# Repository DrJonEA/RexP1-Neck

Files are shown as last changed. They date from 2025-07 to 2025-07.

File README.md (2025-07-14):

# RexP1-Neck
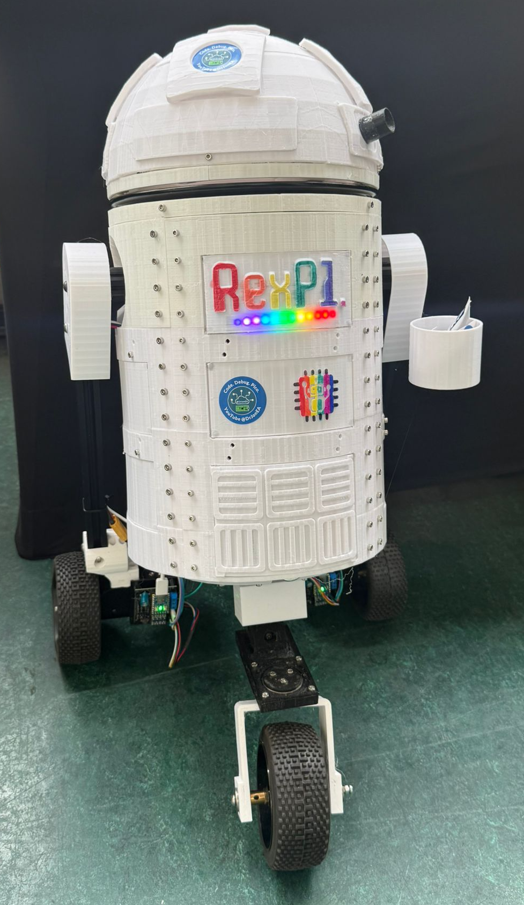
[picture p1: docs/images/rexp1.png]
isolated

Drive wheel for my RexP1 Astro Droid Project based on a RP2040Zero board. This Repo repreents the drive wheel subsystem for RexP1.

Checkout the [videos guides](https://www.youtube.com/playlist?list=PLspDyukWAtRUPNdlktaOdk7os9TfTEFh1) to the project over on my [YouTube Channel DrJonEA](https://youtube.com/@drjonea).
 
## RexP1 Intro
RexP1 is a reimagined Star War's inspired Astro Droid based on the R series Droids. It is based on Raspberry PI 5, RP2040 and RP2350 boards. It's control system is a distributed net based on ROS2 and MicroROS frameworks.

All my work on RexP1 is available to  my sponsors. That includes not just this submodule but all the submodules, the build instructions, PCB designs, STL files, CAD designs and most important acess to me to ask questions. Take a look at the sponsorship button on the github repo.

## The Repo
This repo includes the PCB design for the dome rotation and tilt  with assoicated documentation. It also includes the firmware for a RP2040Zero which acts as a ROS2 Node to control the Dome.

## Libraries
Note libraries have not been included as submodules in this repo. That is because I wanted just a single copy of the libraries in the master repo for RexP1. So take note of the [lib documentation](docs/Libraries.md).

## Build process
The firmware should build like most *complex* Pico SDK firmware projects. Normal procedure:
```
mkdir build
cd build
cmake ..
make
```
If you have ninja use that instead of make for Windows. Just make sure you update the CMakelists.txt to point to your libraries and that the environment variable PICO_SDK_PATH is defined to point to the SDK.

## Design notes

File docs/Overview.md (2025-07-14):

# Project Overview: 
REXP1 is reimagined, modular Star Wars-inspired droid that blends mechanical engineering, electronics, and thematic flair. Designed for both mobility and character, it features a dual-mode rotating body that shifts between relaxed drive possition and alert postures, driven by bus servos and integrated with interactive LED lighting for expressive behavior.

# Key Technical Highlights:

## Dome Rotation: 
Powered by a modified 28BYJ-48 stepper motor configured for two-phase operation and driven via a DRV8825 motor driver. A Hall sensor (A1104) is used for zero-point calibration, ensuring precise rotation positioning.

## Body Tilt Mechanism: 
Built around bus servos with direct UART communication through an RP2040, complemented by a braced gear drive for torque management. Initial gear designs were iterated to improve stability under growing load.

## Microcontroller & Control Firmware: 
The RP2040Zero microcontroller hosts firmware which orchestrates movement via Micro ROS integration. Stepper and servo controls are abstracted into modular classes like Stepper, JointAgent, and LX16A, enabling joint state publishing and jog-based movement control.

## Visual Effects & Expression: 
Equipped with WS2812B (NeoPixel) LED bars managed via a custom LED Bar Agent. Patterns include rainbow sequences and a Knight Rider–inspired "KITT" sweep, with pride-themed color support to reflect community values and demonstration context.

## Expandable Connectivity: 
The PCB (fabricated by PCBWay) includes multiple servo outputs (PWM and UART) and support for additional peripherals, allowing future upgrades like tool arms and sensory modules.

## Creative & Thematic Elements: 
The build fuses classic sci-fi aesthetics with modern electronics, aiming to evolve REX-P1 into a more expressive and interactive robotic character. Jon’s storytelling adds depth, portraying the development journey with humor and candid insights into design challenges.

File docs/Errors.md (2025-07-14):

# Known errors

<ol>
<li>Signal diode is wrong way around on PCB</li>
<li>RexP1 has grown beyond BUSServos for tilting</li>
</ol>

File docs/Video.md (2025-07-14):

# Video Guides

[This video](https://youtu.be/UPuPh0Mcucg) talks about the PCB design for the Dome rotation and tilt mechanism.

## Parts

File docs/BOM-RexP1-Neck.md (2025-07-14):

# Bill of Materials

This is a BOM for the controller PCB. Headerpins will also be needed for some of the connectors.

|Reference |Footprint	 |	Qty	| Link | Notes
|---|---|----|---|---|
|A1|Pololu_Breakout_DRV8825| 1|https://amzn.to/3GIwLjC||
|BS1,BS2|JST_XH_B3B-XH-AM_1x03_P2.50mm_Vertical|2| | For HiWonder LX16A|
|C1|0.1uF C_Disc_D4.7mm_W2.5mm_P5.00mm|1|||
|C2,C3|1000uF CP_Radial_D8.0mm_P5.00mm|2|||
|D2|1N4148|1|https://assets.nexperia.com/documents/data-sheet/1N4148_1N4448.pdff|||
|J1|Stepper JST_XH_B4B-XH-AM_1x04_P2.50mm_Vertical|1|||
|J2|uart0 PinHeader_1x03_P2.54mm_Vertical,"1"|||
|J3|GND to GNDA PinHeader_1x02_P2.54mm_Vertical|1||Allows jumper to connect grounds|
|J4|Hall Sensor PinHeader_1x03_P2.54mm_Vertical|1|||
|J5,SV1,SV2,SV3,SV4,SV5| PinHeader_1x03_P2.54mm_Vertical|6||Used for Servos|
|J6| WS2812B-1 Conn_01x04_Pin|2|||
|P2|12V SCREWTERMINAL-5MM-2|1|||
|P3|6V|SCREWTERMINAL-5MM-2|1|||
|R1|RResistor_THT|1|||
|R2|220R|Resistor_THT|1|||
|R3|10K|Resistor_THT|1|||
|RZ1|RP2040-Zero|RP2040-Zero||1||
|SW1|SW_SPST |1|SW_PUSH_6mm||
|U1|LvlShift2Bi||1|| 2 channel level shifter|
|U2|A1104xLH|1|HAll Sensor||

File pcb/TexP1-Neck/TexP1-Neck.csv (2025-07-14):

Reference | Value | Footprint | Datasheet | Qty | DNP
A1 | Pololu_Breakout_DRV8825 | Module:Pololu_Breakout-16_15.2x20.3mm | https://www.pololu.com/product/2982 | 1
BS1,BS2 | Bus Servo | Connector_JST:JST_XH_B3B-XH-AM_1x03_P2.50mm_Vertical | ~ | 2
C1 | 0.1uF | Capacitor_THT:C_Disc_D4.7mm_W2.5mm_P5.00mm | ~ | 1
C2,C3 | 1000uF | Capacitor_THT:CP_Radial_D8.0mm_P5.00mm | ~ | 2
D2 | 1N4148 | Diode_THT:D_DO-35_SOD27_P7.62mm_Horizontal | https://assets.nexperia.com/documents/data-sheet/1N4148_1N4448.pdf | 1
J1 | Stepper | Connector_JST:JST_XH_B4B-XH-AM_1x04_P2.50mm_Vertical | ~ | 1
J2 | uart0 | Connector_PinHeader_2.54mm:PinHeader_1x03_P2.54mm_Vertical | ~ | 1
J3 | GND to GNDA | Connector_PinHeader_2.54mm:PinHeader_1x02_P2.54mm_Vertical | ~ | 1
J4 | Hall Sensor | Connector_PinHeader_2.54mm:PinHeader_1x03_P2.54mm_Vertical | ~ | 1
J5,SV1,SV2,SV3,SV4,SV5 | Conn_01x03_Pin | Connector_PinHeader_2.54mm:PinHeader_1x03_P2.54mm_Vertical | ~ | 6
J6,WS2812B-1 | Conn_01x04_Pin | Connector_PinHeader_2.54mm:PinHeader_1x04_P2.54mm_Vertical | ~ | 2
P2 | 12V | Connectors:SCREWTERMINAL-5MM-2 | ~ | 1
P3 | 6V | Connectors:SCREWTERMINAL-5MM-2 | ~ | 1
R1 | R | Resistor_THT:R_Axial_DIN0207_L6.3mm_D2.5mm_P10.16mm_Horizontal | ~ | 1
R2 | 220R | Resistor_THT:R_Axial_DIN0207_L6.3mm_D2.5mm_P10.16mm_Horizontal | ~ | 1
R3 | 10K | Resistor_THT:R_Axial_DIN0207_L6.3mm_D2.5mm_P10.16mm_Horizontal | ~ | 1
RZ1 | RP2040-Zero | RP2040-Zero-Kicad:RP2040-Zero |  | 1
SW1 | SW_SPST | Button_Switch_THT:SW_PUSH_6mm | ~ | 1
U1 | LvlShift | JonLib:LvlShift2Bi |  | 1
U2 | A1104xLH | Package_TO_SOT_SMD:SOT-23W | https://www.allegromicro.com/-/media/files/datasheets/a110x-datasheet.ashx | 1

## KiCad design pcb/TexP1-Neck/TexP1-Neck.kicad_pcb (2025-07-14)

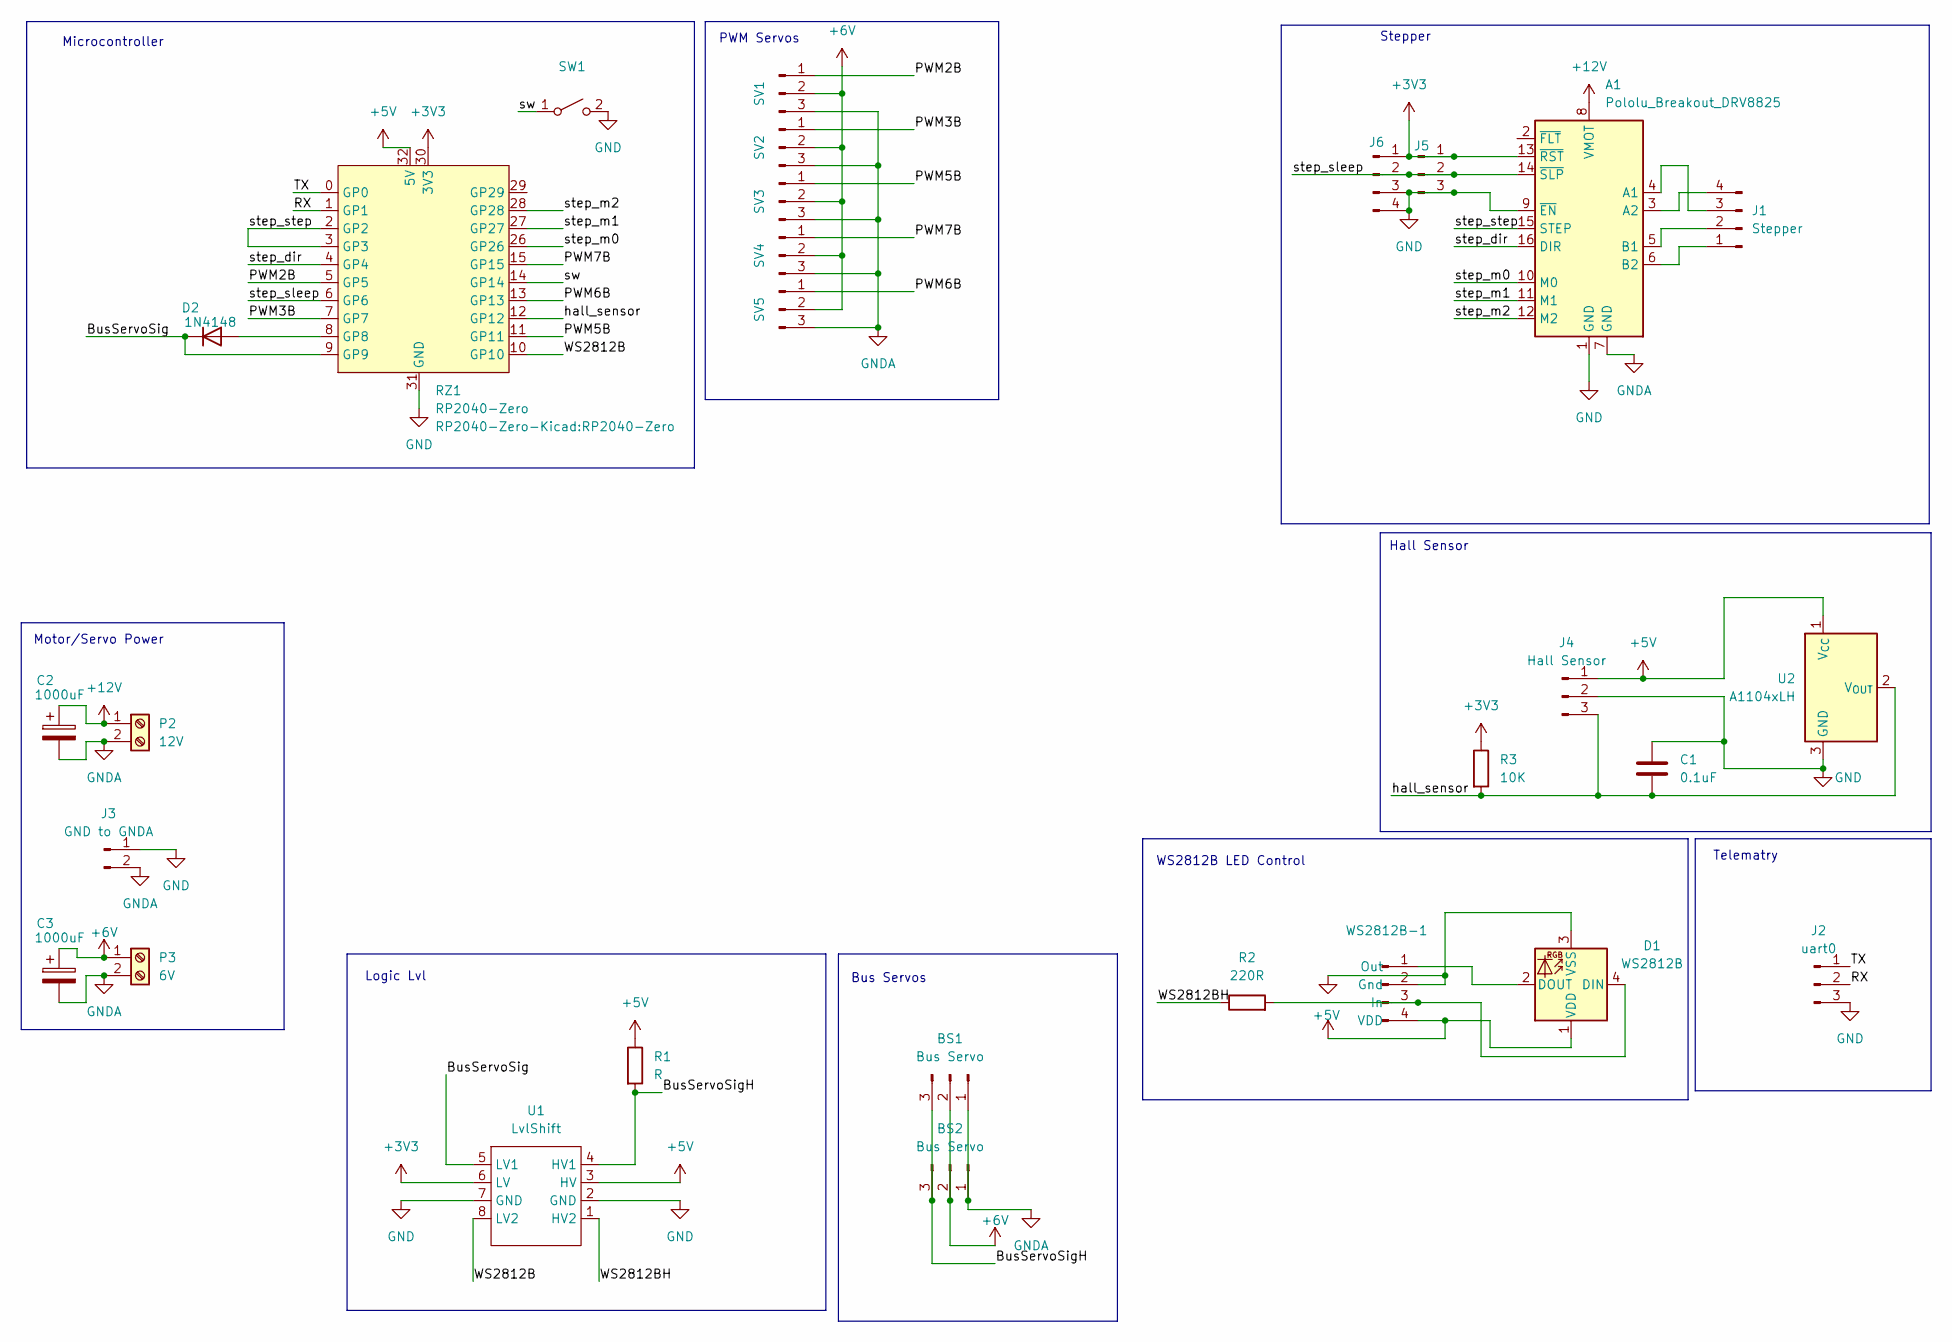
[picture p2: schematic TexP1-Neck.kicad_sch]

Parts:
A1: Pololu_Breakout_DRV8825; Pololu_Breakout-16_15.2x20.3mm
BS1, BS2: Bus Servo; JST_XH_B3B-XH-AM_1x03_P2.50mm_Vertical
C1: 0.1uF; C_Disc_D4.7mm_W2.5mm_P5.00mm
C2, C3: 1000uF; CP_Radial_D8.0mm_P5.00mm
D1: WS2812B; LED_WS2812B_PLCC4_5.0x5.0mm_P3.2mm
D2: 1N4148; D_DO-35_SOD27_P7.62mm_Horizontal
J1: Stepper; JST_XH_B4B-XH-AM_1x04_P2.50mm_Vertical
J2: uart0; PinHeader_1x03_P2.54mm_Vertical
J3: GND to GNDA; PinHeader_1x02_P2.54mm_Vertical
J4: Hall Sensor; PinHeader_1x03_P2.54mm_Vertical
J5: Conn_01x03_Pin; PinHeader_1x03_P2.54mm_Vertical
J6: Conn_01x04_Pin; PinHeader_1x04_P2.54mm_Vertical
P2: 12V; SCREWTERMINAL-5MM-2
P3: 6V; SCREWTERMINAL-5MM-2
R1: R; R_Axial_DIN0207_L6.3mm_D2.5mm_P10.16mm_Horizontal
R2: 220R; R_Axial_DIN0207_L6.3mm_D2.5mm_P10.16mm_Horizontal
R3: 10K; R_Axial_DIN0207_L6.3mm_D2.5mm_P10.16mm_Horizontal
RZ1: RP2040-Zero
SV1, SV2, SV3, SV4, SV5: Conn_01x03_Pin; PinHeader_1x03_P2.54mm_Vertical
SW1: SW_SPST; SW_PUSH_6mm
U1: LvlShift; LvlShift2Bi
U2: A1104xLH; SOT-23W
WS2812B-1: Conn_01x04_Pin; PinHeader_1x04_P2.54mm_Vertical

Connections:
+3V3: A1.13 (~RST), J5.1, J6.1, R3.1, RZ1.30 (3V3), U1.6 (LV)
+5V: D1.1 (VDD), J4.1, R1.1, RZ1.32 (5V), U1.3 (HV), U2.1 (V_{CC}), WS2812B-1.4 (VDD)
+6V: BS1.2, BS2.2, C3.1, P3.1, SV1.2, SV2.2, SV3.2, SV4.2, SV5.2
+12V: A1.8 (VMOT), C2.1, P2.1
/BusServoSig: D2.1 (K), RZ1.9 (GP9), U1.5 (LV1)
/BusServoSigH: BS1.3, BS2.3, R1.2, U1.4 (HV1)
/PWM2B: RZ1.5 (GP5), SV1.1
/PWM3B: RZ1.7 (GP7), SV2.1
/PWM5B: RZ1.11 (GP11), SV3.1
/PWM6B: RZ1.13 (GP13), SV5.1
/PWM7B: RZ1.15 (GP15), SV4.1
/RX: J2.2, RZ1.1 (GP1)
/TX: J2.1, RZ1.0 (GP0)
/WS2812B: RZ1.10 (GP10), U1.8 (LV2)
/WS2812BH: R2.1, U1.1 (HV2)
/hall_sensor: C1.2, J4.3, R3.2, RZ1.12 (GP12), U2.2 (V_{OUT})
/step_dir: A1.16 (DIR), RZ1.4 (GP4)
/step_m0: A1.10 (M0), RZ1.26 (GP26)
/step_m1: A1.11 (M1), RZ1.27 (GP27)
/step_m2: A1.12 (M2), RZ1.28 (GP28)
/step_sleep: A1.14 (~SLP), J5.2, J6.2, RZ1.6 (GP6)
/step_step: A1.15 (STEP), RZ1.2 (GP2), RZ1.3 (GP3)
/sw: RZ1.14 (GP14), SW1.1 (A)
GND: A1.1 (GND), A1.9 (~EN), C1.1, D1.3 (VSS), J2.3, J3.1, J4.2, J5.3, J6.3, J6.4, RZ1.31 (GND), SW1.2 (B), U1.2 (GND), U1.7 (GND), U2.3 (GND), WS2812B-1.2 (Gnd)
GNDA: A1.7 (GND), BS1.1, BS2.1, C2.2, C3.2, J3.2, P2.2, P3.2, SV1.3, SV2.3, SV3.3, SV4.3, SV5.3
unnamed: A1.4 (A1), J1.3
unnamed: A1.3 (A2), J1.4
unnamed: A1.5 (B1), J1.2
unnamed: A1.6 (B2), J1.1
unnamed: D2.2 (A), RZ1.8 (GP8)
unnamed: D1.4 (DIN), R2.2, WS2812B-1.3 (In)
unnamed: D1.2 (DOUT), WS2812B-1.1 (Out)

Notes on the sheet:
Telematry
PWM Servos
Bus Servos
Logic Lvl
Hall Sensor
WS2812B LED Control
Stepper
Microcontroller
Motor/Servo Power

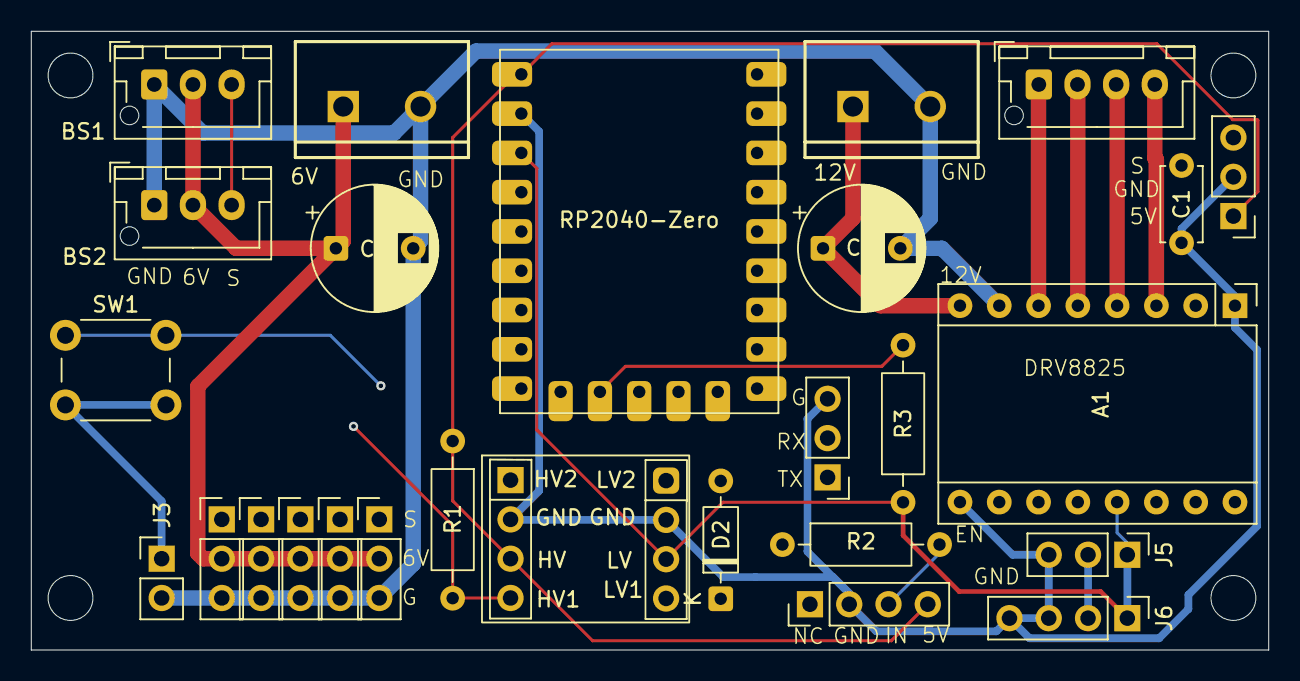
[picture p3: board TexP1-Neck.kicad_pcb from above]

Board: 4 copper layers, 80.0 x 40.0 mm, 27 parts (0 on the bottom side), 31 nets.

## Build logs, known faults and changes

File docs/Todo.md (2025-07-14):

# Todo List

<ol>
<li>Tilt mechanism, though that may move somewhere else</li>
</ol>

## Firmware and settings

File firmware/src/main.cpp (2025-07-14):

/***
 * Demo
 * Uses FreeRTOS Task
 * Jon Durrant
 * 9-Jan-2025
 */


#include "pico/stdlib.h"

#include "FreeRTOSConfig.h"
#include "FreeRTOS.h"
#include "task.h"
#include <stdio.h>

#include "BlinkAgent.h"


#include <math.h>

#include "AstroDroidConfig.h"

extern"C"{
#include "pico/stdio/driver.h"
#include "pico/stdio.h"
#include "pico/stdio_usb.h"
#include "pico/stdio_uart.h"
}

#include "uRosEntities.h"
#include "PubEntities.h"
#include "uRosBridge.h"

#include "ConfigEntity.h"
#include "AstroEntities.h"
#include "NVSJson.h"

#include "Stepper.h"
#include "JointAgent.h"
#include "LX16A.h"

#include "LEDBarAgent.h"



//Standard Task priority
#define TASK_PRIORITY		( tskIDLE_PRIORITY + 1UL )


//Blink Delay
#define DELAY				500


/***
 * Main task to blink external LED
 * @param params - unused
 */
void mainTask(void *params){

	printf("Main task started\n");

	//Get Node name from NVS
	NVSJson *nvs = NVSJson::getInstance();
	size_t nameLen = nvs->size(ROS2_NODE);
	char *name =  (char *)pvPortMalloc(nameLen);
	if (nvs->get_str ( ROS2_NODE,  name,  &nameLen) != NVS_OK){
		printf("ERROR Retrieving ROS2_NODE from NVS\n");
		nvs->printNVS();
	}

	//Config
	AstroEntities entities;
	ConfigEntity confEntities;
	entities.addEntity(&confEntities);

	LEDBarAgent leds;
	leds.start("LEDS", TASK_PRIORITY);

	//Stepper
	Stepper xStep(
			GP_STEP,
			GP_DIR,
			GP_STEP_DETECT,
			GP_HALL
			);
	xStep.configMicroStepGp(GP_M0, GP_M1, GP_M2);
	xStep.configSleepGp(GP_SLEEP);
	uint maxSteps = 381904/32;
	xStep.setMaxSteps(maxSteps);
	xStep.findZero();
	while (!xStep.isStopped()){
		vTaskDelay(100);
	}

	//Servo
	//LX16A lx16a;
	//lx16a.config(GP_LX16A_TX, GP_LX16A_RX);
	//lx16a.setLimitRad(NECK_LX16A,  0.86,  2.10);

	//Joint Agent
	JointAgent joints;
	joints.addStepper(&xStep);
	//joints.addLX16A(&lx16a);
	entities.addEntity(&joints);

	//Start up a uROS Bridge
	uRosBridge *bridge = uRosBridge::getInstance();
	bridge->setNodeName(name);

	//PubEntities entities;
	bridge->setuRosEntities(&entities);
	//bridge->setLed(DEBUG_LED1);
	bridge->setLed(ZERO_NEOPIXEL);
	bridge->start("Bridge",  TASK_PRIORITY+2);

	joints.start("Joints", TASK_PRIORITY);

	for (;;){
		vTaskDelay(3000);
	}


}




/***
 * Launch the tasks and scheduler
 */
void vLaunch( void) {

	//Start blink task
    TaskHandle_t task;
    xTaskCreate(mainTask, "MainThread", 1024*4, NULL, TASK_PRIORITY, &task);

    /* Start the tasks and timer running. */
    vTaskStartScheduler();
}

/***
 * Main
 * @return
 */
int main( void )
{
	//Setup serial over USB and give a few seconds to settle before we start
    stdio_init_all();
    stdio_filter_driver(&stdio_uart);
    sleep_ms(2000);
    printf("GO\n");

    //Start tasks and scheduler
    const char *rtos_name = "FreeRTOS";
    printf("Starting %s on core 0:\n", rtos_name);
    vLaunch();


    return 0;
}

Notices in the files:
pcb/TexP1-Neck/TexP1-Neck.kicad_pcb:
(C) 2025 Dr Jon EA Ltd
